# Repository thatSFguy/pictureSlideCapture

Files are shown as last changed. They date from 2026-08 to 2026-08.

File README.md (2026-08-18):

# Film Scanning Rig

> ## ⚠️ Alpha
> It has completed a real production run end-to-end on the author's setup
> (Canon EOS 400D on a Raspberry Pi appliance), but it's been tested on exactly
> one camera and rig, has **no authentication** (designed for a trusted home
> LAN), and interfaces may change. Use at your own risk; expect rough edges.

Digitize 35mm slides and negatives with a tethered Canon DSLR — a web app you
drive from any browser to place a slide, capture it, and review the batch.

> **Status:** proven in production — the author's 35mm slide collection has been
> fully digitized with this rig (hands-free sensor-triggered batches on the Pi
> appliance, hundreds of slides per session). The negatives workflow (RAW preset,
> inversion-ready files) is built but hasn't had a production run yet, and the
> automated XY gantry is deferred. See [CLAUDE.md](CLAUDE.md) for hardware/dev
> notes.

## What it is

A DSLR is mounted over a backlit high-CRI light pad; film is placed in a holder
under the lens and triggered over USB. The host runs a small **stdlib-only
Python web app** (`capture_server.py`) that talks to the camera via `gphoto2`
and serves a phone/tablet/desktop UI. No live view on the target camera (Canon
EOS 400D / Rebel XTi), so the workflow is shoot → review, optimized for volume.

In production it ran fully hands-free: a continuously running motor pushes each
new slide into place, and an optical switch fires the capture as it arrives —
see [Optical sensor trigger](#optical-sensor-trigger-optional) for the mechanism.

## The rig in action

https://github.com/user-attachments/assets/5fd9c2e0-e4c6-4333-81f3-d29baf97b7d2

*The rotary pusher feeding slides while the sensor fires each capture —
fully hands-free.*

## What you need

- A **64-bit-capable Raspberry Pi** (Pi Zero 2 W or newer — the Zero 2 W is the
  reference target), a microSD card, and power. The image is 64-bit (arm64),
  so the single-core ARMv6 Pi Zero W / Pi 1 won't boot it.
- A **Canon DSLR supported by gphoto2** (built and proven on the EOS 400D /
  Rebel XTi) and a USB OTG cable/adapter for the Pi.
- A **high-CRI backlight** under the film, and — for the hands-free feeder —
  the [3D-printed parts](#3d-printed-parts), a small DC motor, and an optical
  break-beam sensor.

No Pi? The app also runs on any Linux/macOS machine — see
[Appendix B](#appendix-b--running-on-a-laptop-instead).

## Quick start — flash the appliance

1. Download the latest `slidescanner-*-arm64.img.xz` from
   [Releases](https://github.com/thatSFguy/pictureSlideCapture/releases) and
   flash it to the SD card with Raspberry Pi Imager.
2. On the camera: set **Communication → PC connection**, the mode dial to
   **M**, and disable auto power-off (an AC dummy-battery coupler beats a
   decades-old battery for long sessions).
3. Boot the Pi. On first boot it raises a **`slidescanner-XXXX`** WiFi access
   point — join it from your phone and enter your home WiFi details.
4. The Pi reconnects to your network. Plug the camera into the Pi, open
   **`http://slidescanner.local:8080`** from any phone/tablet/laptop on the
   LAN, and scan.

Prefer to build the SD image yourself? See
[Appendix A](#appendix-a--building-the-sd-image-yourself).

### Updating

Once deployed, update from the browser: **Setup → System → Check for updates**.
It pulls the latest **release tag** and restarts — no SSH, no reflash. (This
updates the *app* only; changes to the OS image or provisioning still need a new
flashed image.) Requires the Pi to have internet access.

## Using the app — three modes

- **Setup** (once per batch): pick **Slides** or **Negatives** preset, set a
  group name, fine-tune exposure, take a **Test shot** to check it, then
  *Start capturing*. Setup also lists **every group on the device** — reopen an
  old group to review/download it, or delete it outright (renaming a group never
  strands its files).
- **Capture** (the fast loop): large last shot, a glanceable exposure verdict,
  and a running count. Keyboard-first for high volume.
- **Review** (after): thumbnail grid with exposure flags, filter to flagged
  frames, caption/delete/download individual images, download the whole group
  as a zip, or clear the group once it's safely downloaded.

> Tip: `?mode=capture` / `?mode=review` in the URL deep-links a mode — handy as
> a tablet bookmark straight into the capture loop.

**Setup** — presets, group manager, exposure, test shot, sensor trigger and
brightness correction:

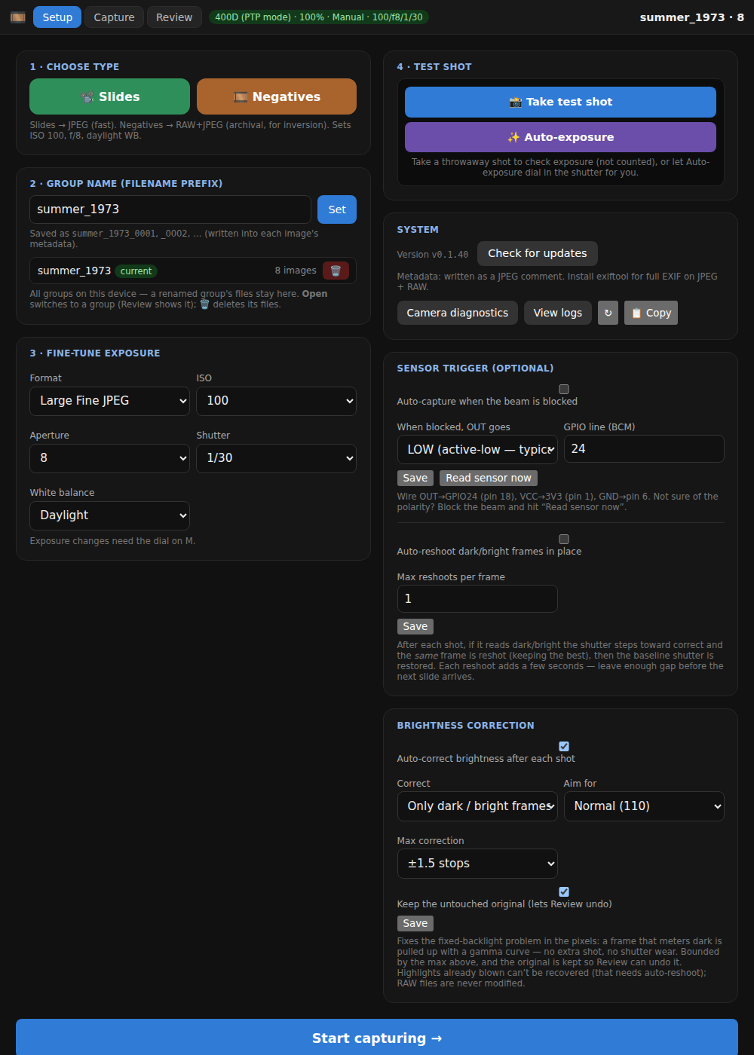
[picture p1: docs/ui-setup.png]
Setup mode: presets, group name + group list, exposure dropdowns, test shot, system, sensor trigger, brightness correction


**Capture** — the whole loop on one screen: last shot, exposure verdict, count,
one big button (or the spacebar, or the optical sensor):

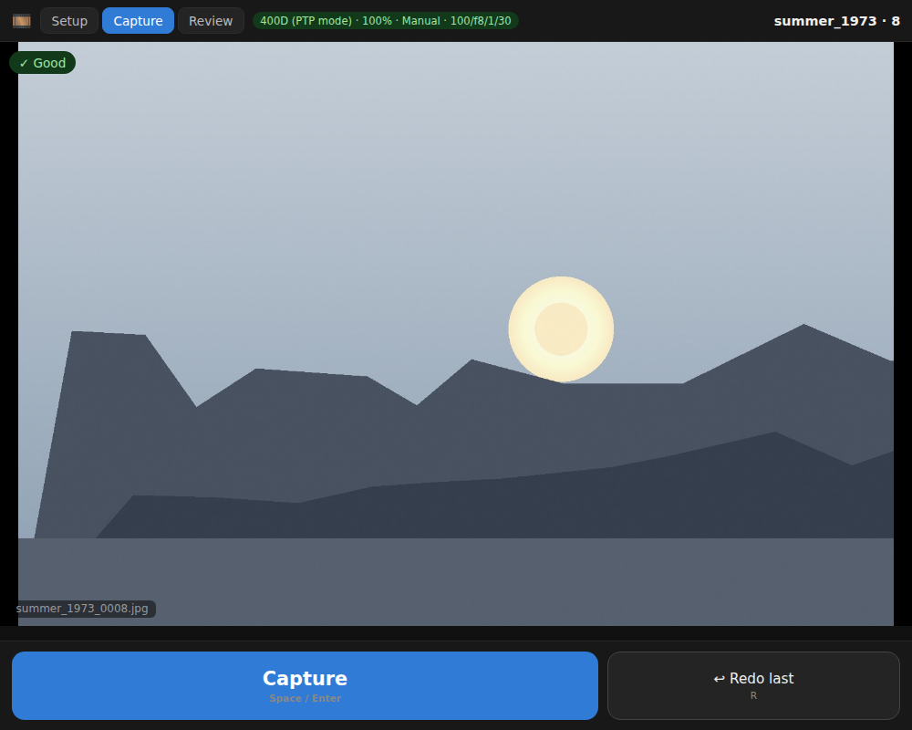
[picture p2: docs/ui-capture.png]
Capture mode: large last-shot preview with exposure chip, running count, Capture and Redo-last buttons


**Review** — the grid with per-frame exposure dots and captions:

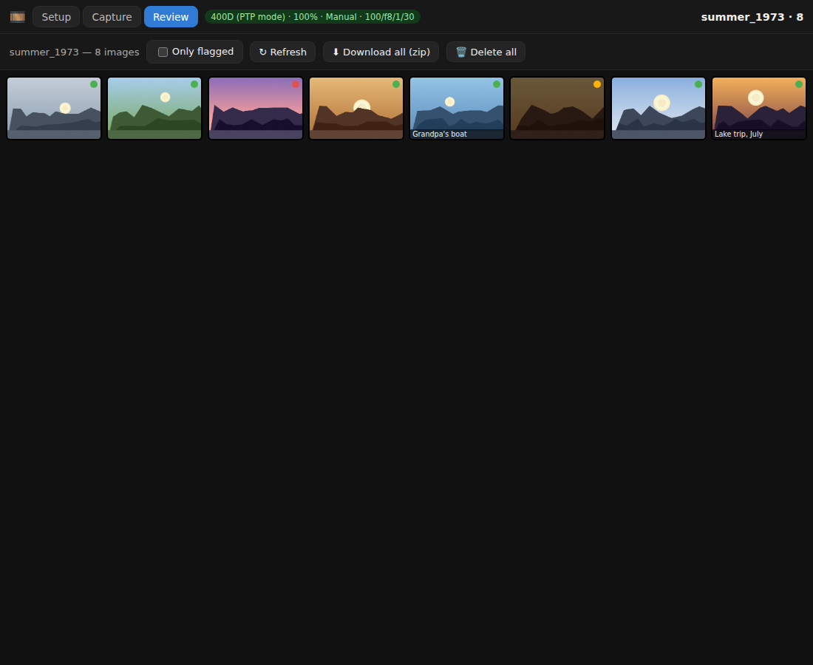
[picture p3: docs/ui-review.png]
Review mode: thumbnail grid with exposure flags, captions, flagged-only filter, zip download and delete-all


*(Screenshots show a demo group served by the app on a dev machine — a stub
camera and generated placeholder images, since the real scans belong to the
family album.)*

### Keyboard shortcuts

| Key | Action |
|-----|---|
| `Space` / `Enter` | Capture |
| `R` / `Backspace` | Redo last (delete + recapture) |
| `←` / `→` | Browse recent (Capture) / prev-next (Review lightbox) |
| `[` / `]` | Go to Setup / Review |
| `Esc` | Close the Review lightbox |
| `Delete` | Delete (Review lightbox) |

## Brightness correction

Slide density varies a lot, and you can't re-dial the light pad for every frame.
Two independent fixes, both automatic — use either or both:

| | Auto-reshoot (optical) | Brightness correction (digital) |
|---|---|---|
| How | Steps the shutter and re-fires the **same** slide, keeping the best | Re-encodes the saved JPEG with a gamma curve onto a target brightness |
| Cost | A whole extra capture cycle (~18 s) + shutter actuation | A few seconds of CPU, in the background — the capture loop never waits |
| Best at | Blown highlights, very dense slides | The routine ±1–2 stop misses |
| Limits | Slow; needs a gap before the next slide | Can't recover detail that was already clipped |

Both live in **Setup**. Brightness correction is on by default for *flagged*
frames only (switch it to "every frame" for an even-looking batch), is bounded
to ±1.5 stops so a legitimately dark night shot can't be wrecked, and keeps the
untouched capture in `captures/originals/` — Review's lightbox has **👁 Original**
to compare and **↩ Undo brighten** to put it back. RAW files are never modified;
for negatives the CR2 is the deliverable and inversion happens in post.

The download-all zip carries those untouched copies in an `originals/` folder, so
downloading and then clearing the group never bakes a correction in permanently.
(Add `?originals=0` to the zip URL to skip them.)

Brightness correction needs one system package (`python3-pil`) that the code
update can't carry — it's a compiled library, not Python source. **You don't
need SSH or a re-flash for it:** if it's missing, Setup shows
**⬇ Install brightness support**, and the scanner fetches it itself over WiFi in
a minute or two (no restart). New SD-card images ship with it already.

## Recommended camera settings

ISO 100, f/8, Manual mode, fixed (Daylight) white balance; **JPEG** for slides,
**RAW+JPEG** for negatives (RAW is essential for inversion). Shutter is the one
value dialed in per session against your light pad using the Test shot +
exposure aid. Focus once, manually, on the film plane. Full rationale in
[CLAUDE.md](CLAUDE.md).

## Optical sensor trigger (optional)

The production rig runs fully hands-free, and the division of labor is simple:

- **The motor just runs.** A continuously running motor — its own power supply
  and a manual speed knob; the Pi neither powers nor controls it — turns a
  rotary arm that pushes the next slide into place in front of the lens,
  revolution after revolution.
- **An optical switch takes the picture.** A 3-pin break-beam sensor is tripped
  once per revolution as the arm passes; that edge is the capture trigger —
  beam blocked → shot fired (`trigger.py`, off by default).

The pace is therefore set on the motor's speed knob, not in software: turn it
down until the camera's sensor-to-shutter latency reliably beats the arm coming
around to push the next slide in. Run that way, the rig captured hundreds of
slides per session for hours with no browser open — that's how the author's
whole collection was scanned.

### Wiring — Raspberry Pi 40-pin header

The board's header usually isn't silk-screened with pin numbers. **Pin 1 is the
square solder pad** (nearest the corner); pins count in pairs down the header —
odd numbers in one row, even in the other.

<p align="center">
  Raspberry Pi 40-pin header pinout; pin 1 (3V3) = VCC, pin 6 = GND, pin 18 (GPIO24) = OUT
</p>

| Sensor wire | Connect to | Physical pin |
|---|---|---|
| **VCC** | **3V3** | **1** |
| **GND** | **Ground** | **6** |
| **OUT** | **GPIO24** | **18** |

⚠️ **Power the sensor from 3V3 (pin 1), not 5V.** The Pi's GPIO is **3.3V-only
and not 5V-tolerant** — a 5V-powered sensor can swing OUT to 5V and damage the
input. Most IR/photo-interrupter modules run fine at 3.3V. Only if yours
*requires* 5V (pins 2/4) do you power it there, and then you **must** drop OUT to
3.3V (voltage divider or level shifter) before pin 18. GPIO24 is used because it
avoids the pins `advance.py` reserves (BCM 17/18/22/27).

### Enabling + polarity

Sensor OUT idle state varies part-to-part, so the trigger polarity is a setting.
In **Setup → Sensor trigger**: tick *Auto-capture when the beam is blocked*, pick
whether OUT goes **LOW** (active-low, the typical open-collector case — default)
or **HIGH** when blocked, set the GPIO line, and **Save**. Not sure which?
**Block the beam and hit “Read sensor now”** — it reads the raw 0/1 so you can
tell active-low (obstructed = 0) from active-high (obstructed = 1). A short
cooldown debounces bounce and avoids a double-fire during the download.

CLI equivalents: `--sensor`, `--sensor-line N` (BCM, default 24),
`--sensor-active-high`. Needs `gpiod` (`sudo apt install gpiod`; already in the
appliance image). Sensor captures share the camera lock with the UI, so a sensor
shot and a button press never overlap. libgpiod **v1 and v2** are both supported
(the CLI syntax differs between them; the app auto-detects the version).

To sanity-check wiring by hand from a shell (libgpiod **v2**, recent Pi OS):

```bash
gpioget -c gpiochip0 24               # prints 24=inactive / 24=active
gpiomon -c gpiochip0 -e falling 24    # block/clear the beam → an event per edge
```

On older **v1** it's `gpioget gpiochip0 24` / `gpiomon --falling-edge gpiochip0 24`.

## 3D-printed parts

Everything printed for the feeder and camera rig is in
[`3D_Files/`](3D_Files/): ready-to-slice **STLs** plus the **FreeCAD sources**
(`.FCStd`), so any dimension can be tweaked for your own camera, motor, or
light before printing.

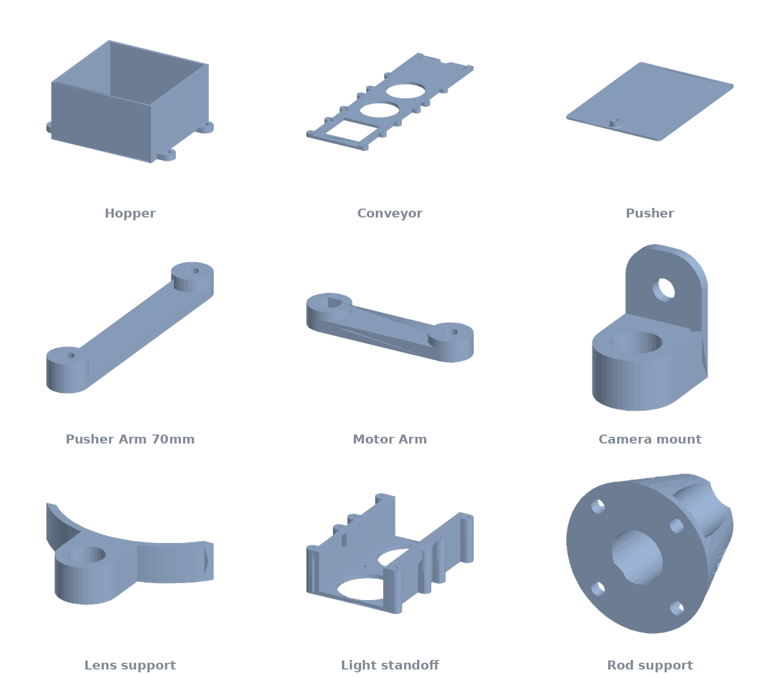
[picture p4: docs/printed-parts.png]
The nine printed parts: Hopper, Conveyor, Pusher, Pusher Arm 70mm, Motor Arm, Camera mount, Lens support, Light standoff, Rod support


| Part | Role |
|---|---|
| Hopper | Holds the stack of slides waiting to be fed |
| Conveyor | The track the slides travel along, over the backlight — the drive motor mounts directly to it |
| Motor Arm | The crank on the motor shaft — this is also what sweeps past the optical sensor once per revolution |
| Pusher Arm 70mm | Connecting link from the crank to the pusher |
| Pusher | The plate that shoves the next slide out of the hopper and into place |
| Camera mount / Rod support | Hold the DSLR on its support rod above the film plane |
| Lens support | Steadies the lens barrel |
| Light standoff | Spaces the backlight below the conveyor |

## Files

| File | Role |
|---|---|
| `capture_server.py` | The web app (HTTP server + embedded UI + all endpoints) |
| `camera.py` | gphoto2 wrapper: detect, get/set config, capture, retries |
| `jpegstats.py` | Pure-stdlib JPEG brightness reader for the exposure aid |
| `brightness.py` | Digital brightness correction: gamma-curves a flagged frame onto a target, keeps the original (needs `python3-pil`) |
| `advance.py` | Auto slide-advance output (stub): capture → advance → repeat, settings-driven (motor+switch / stepper); default off |
| `trigger.py` | Optical-sensor capture trigger: auto-captures on the beam-blocked edge, polarity configurable; default off |
| `scanner.py` | Gantry dead-reckoning batch loop (deferred automation phase) |
| `CLAUDE.md` | Detailed hardware, protocol, and development notes |
| `3D_Files/` | Printable parts for the feeder + camera rig (STL + FreeCAD sources) |

Captured images and per-group sidecars (`captions.json`, `exposure.json`,
`config.json`) are written under `captures/` and are git-ignored, as is
`captures/originals/` (pre-correction copies).

## Post-processing

Negatives require inversion — [Negative Lab Pro](https://www.negativelabpro.com/)
(Lightroom), FilmLab, or darktable's negadoctor. Slides need only minor
correction.

## Roadmap

**The project is done.** It accomplished what it was built for — the author's
35mm slide collection is digitized — and is now in maintenance mode. No further
development is planned.

What it delivered:

- [x] Camera tethering + full-res capture over USB
- [x] Web capture app: presets, exposure aid, digital brightness correction,
      captions, review/cull, export, group management
- [x] Raspberry Pi flash-and-go appliance: CI-built SD image, Comitup WiFi
      provisioning, in-app self-update and diagnostics — no SSH needed
- [x] Physical rig: high-CRI backlight, rotary slide pusher (continuously
      running motor with a manual speed knob — not Pi-controlled), optical
      break-beam capture trigger
- [x] **Production: the whole slide collection scanned end-to-end** —
      multi-hour hands-free sensor-triggered sessions, hundreds of slides per
      session, brightness correction cleaning up the dense frames

Not planned (left here in case the project is ever picked back up):

- Negatives production run — the presets + RAW pipeline are built and should
  work, but never got used in anger
- Auto slide-advance (`advance.py`) — stub + API exist, but the production rig
  proved it unnecessary: the free-running motor plus the optical switch cover it
- Automated XY gantry (GRBL, `scanner.py`) — was the plan for negative strips
- Security hardening (auth/PIN, sudo allowlist, firewall, port 80) — only
  matters if the app ever serves an untrusted network; today it's a trusted
  home LAN behind NAT
- CI on native ARM runners instead of QEMU

## Appendix A — Building the SD image yourself

The prebuilt Release images are produced by CI (GitHub Actions builds a
flashable `.img` on every tag), and the same kit runs locally:
`deploy/setup_pi.sh` installs gphoto2, camera permissions, Comitup for WiFi
provisioning, and the systemd service into a stock Raspberry Pi OS Lite image.
The full two-phase guide is in [`deploy/DEPLOY.md`](deploy/DEPLOY.md).

Note the in-app self-update only ships app code — changes to the OS image or
provisioning need a freshly built (or freshly downloaded) image.

## Appendix B — Running on a laptop instead

Any Linux machine works, and macOS too (Windows doesn't — gphoto2 has no
Windows port, which is much of why the Pi appliance exists). You need:

- [`gphoto2`](http://gphoto.org/) — `sudo apt install gphoto2`
- Python 3 (standard library only — **nothing to `pip install`**)
- Optional: `python3-pil` (`sudo apt install python3-pil`) for automatic
  brightness correction; without it that feature reports itself unavailable and
  everything else runs unchanged.
- Optional: `exiftool` (`sudo apt install libimage-exiftool-perl`) for full EXIF
  metadata; without it the app writes a JPEG comment instead.

```bash
sudo apt install gphoto2
python3 capture_server.py            # then open http://localhost:8080
```

Options: `--port 8080`, `--out-dir ./captures`, `--prefix trip72`, `--no-setup`.

The camera-menu settings from the Quick start (PC connection, dial on **M**,
auto power-off disabled) apply here too. The optical sensor trigger and the
GPIO wiring are Pi-only — on a laptop you capture with the button, the
spacebar, or `?mode=capture` bookmarked on a tablet.

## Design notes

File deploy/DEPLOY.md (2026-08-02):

# Deploying on a Raspberry Pi Zero 2 W

> The CI image is **64-bit (arm64)**. **Minimum board: a 64-bit-capable Pi
> (Zero 2 W or newer)** — the single-core ARMv6 Zero W / Pi 1 are no longer
> supported. The per-shot cycle is partly CPU-bound (Python + exiftool), which
> the Zero 2 W's quad-core A53 handles far better than the old ARMv6 board; the
> rest is bound by the camera's ~1.7 MB/s USB transfer.

Goal — the appliance flow:

> **Flash a card → plug the Pi in → it raises a WiFi AP → connect and enter your
> network → it reconnects → scan at `http://slidescanner.local:8080`.**
> No SSH, no config files, no scripts on the end card.

There's a catch that shapes everything below: a blank card can't `apt install`
Comitup/gphoto2 without a network. So this is **two phases**:

- **Part A — build the appliance image, once.** Install everything on a Pi, then
  save that card as a reusable image.
- **Part B — flash that image and go.** This is the zero-config flow above, and
  it's what you (or anyone) do from then on.

> Why the Zero 2 W's 512 MB RAM is enough: the app is stdlib-only Python, the
> zip download streams, and thumbnails read only the file head. (arm64 uses a
> little more RAM than 32-bit, but the app's footprint is small.) Part of the
> per-shot time is the camera's ~1.7 MB/s USB transfer, which no board fixes.

## Getting the appliance image

Two ways to produce the `slidescanner.img`:

- **CI (recommended).** GitHub Actions builds it for you — see
  [`.github/workflows/build-image.yml`](../.github/workflows/build-image.yml).
  Run it manually (*Actions → Build Pi image → Run workflow*) to get a
  build artifact, or push a `v*` **tag** to attach the compressed image to a
  **Release**. The repo (and your app) are baked in, so there's no private-repo
  copy step. **Set the repo Actions variable `SSH_AUTHORIZED_KEYS`** to your
  public key(s) first (*Settings → Secrets and variables → Actions → Variables*)
  — the appliance's `scanner` user is **key-only**; without it you can't SSH in.
  Then jump to **Part B**.
- **Locally**, following **Part A** below.

## Hardware

- Pi Zero 2 W + a good micro-SD (32 GB+; images live on it).
- **micro-USB-OTG → USB-A adapter** for the camera (data port is micro-USB OTG);
  power via the *separate* PWR port.
- Camera on an **AC coupler**, dial on **M**, Communication = **PC connection**,
  auto-power-off **disabled**.

---

## Part A — Build the appliance image (done once)

You need a network *for this build only*. It won't be needed on the finished
image.

1. **Flash a build card.** Raspberry Pi Imager → *Raspberry Pi OS Lite
   (**64-bit**, Bookworm)* — matches the CI image; requires a 64-bit-capable
   board (Zero 2 W or newer). In OS customisation set: hostname
   `slidescanner`, a username + password, enable **SSH**, and **your WiFi**
   (temporary — for the build).

2. **Get the project onto the Pi.** The GitHub repo is private, so from your
   machine:
   ```bash
   scp -r pictureSlideCapture <user>@slidescanner.local:~/
   ```
   (or authenticate `git`/`gh` on the Pi and clone it.)

3. **Install everything:**
   ```bash
   ssh <user>@slidescanner.local
   cd ~/pictureSlideCapture
   sudo bash deploy/setup_pi.sh
   ```
   This installs gphoto2, the camera udev rule (+ `plugdev`), **Comitup**, the
   hostname, and the `slidescanner` systemd service (port 8080).

4. **Verify** (plug the camera in, power it on):
   ```bash
   systemctl status slidescanner        # active?
   gphoto2 --auto-detect                # camera seen?
   ```
   Browse from another device to `http://slidescanner.local:8080` and take a
   test shot.

5. **Make the image "clean"** so a fresh flash raises the AP instead of joining
   the build WiFi. Remove the saved WiFi so no network is "known":
   ```bash
   nmcli -t -f NAME connection show                 # find your build SSID
   sudo nmcli connection delete "<your-build-ssid>"
   ```
   (Optional tidy-up: `sudo apt clean`, `sudo journalctl --rotate --vacuum-time=1s`.)
   Then shut down: `sudo shutdown -h now`.

6. **Capture the image.** Pull the card, put it in your computer, and save it:
   - Linux/macOS: `sudo dd if=/dev/<card> of=slidescanner.img bs=4M status=progress`
     (then optionally shrink with [PiShrink](https://github.com/Drewsif/PiShrink)).
   - Or use Raspberry Pi Imager / Win32DiskImager "read" to a `.img`.

   `slidescanner.img` is now your reusable appliance image.

---

## Part B — Flash and go (the actual flow)

1. **Flash** `slidescanner.img` to any card (Raspberry Pi Imager → *Use custom*).
   No customisation, no WiFi — flash it as-is.
2. **Plug in** the Pi (and the camera via the OTG adapter). Power on.
3. **Join the AP.** With no known network, Comitup raises WiFi named
   **`slidescanner-XXXX`**. On a phone/laptop, connect to it.
4. **Set your network.** A portal opens (or browse to `http://10.41.0.1`); pick
   your WiFi and enter the password. The Pi joins it and drops the AP.
5. **Scan.** Reconnect your device to that same WiFi and open
   **`http://slidescanner.local:8080`**.

Moving it to a new place later? Same thing — it doesn't recognise the new WiFi,
so it raises `slidescanner-XXXX` again; re-enter credentials.

---

## Everyday use

Setup → pick Slides/Negatives, name the group, dial in the shutter with a Test
shot, Start capturing. Offload with **Review → Download all (zip)**, then delete
the group to free the SD card.

## Service management (on the Pi)

```bash
systemctl status slidescanner
journalctl -u slidescanner -f
sudo systemctl restart slidescanner   # after updating code
```

## Notes / gotchas

- **Port 8080** — Comitup's portal owns port 80, so the scanner URL carries
  `:8080`.
- **Storage** — captures live in `~/captures` on the SD card; offload + delete
  for big RAW jobs (or add a USB stick via a powered OTG hub).
- **Comitup** manages NetworkManager and can be finicky across OS revisions; if
  the AP or reconnect misbehaves, check its docs. Confirm `nmcli device` shows
  wlan0 managed.
- Written without a Pi on hand to test — treat the first build as a shakedown.

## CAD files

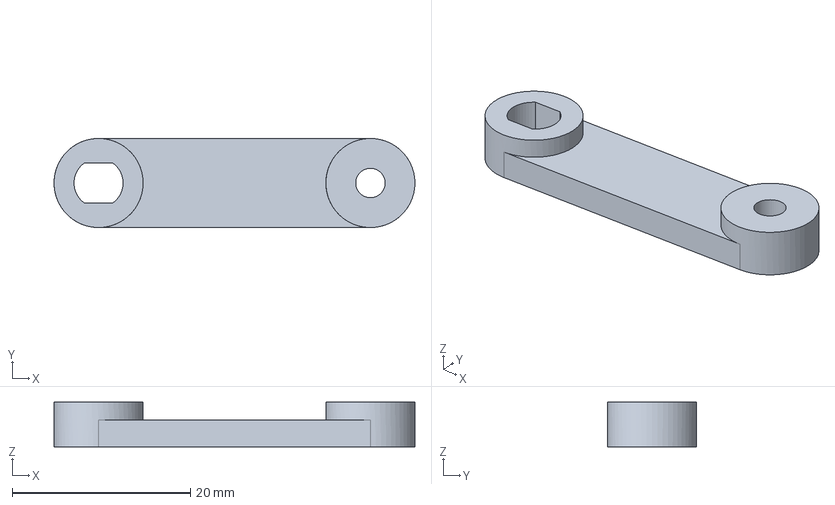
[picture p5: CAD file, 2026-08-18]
3D_Files/Motor Arm.FCStd
40.5 x 10.0 x 5.00 mm

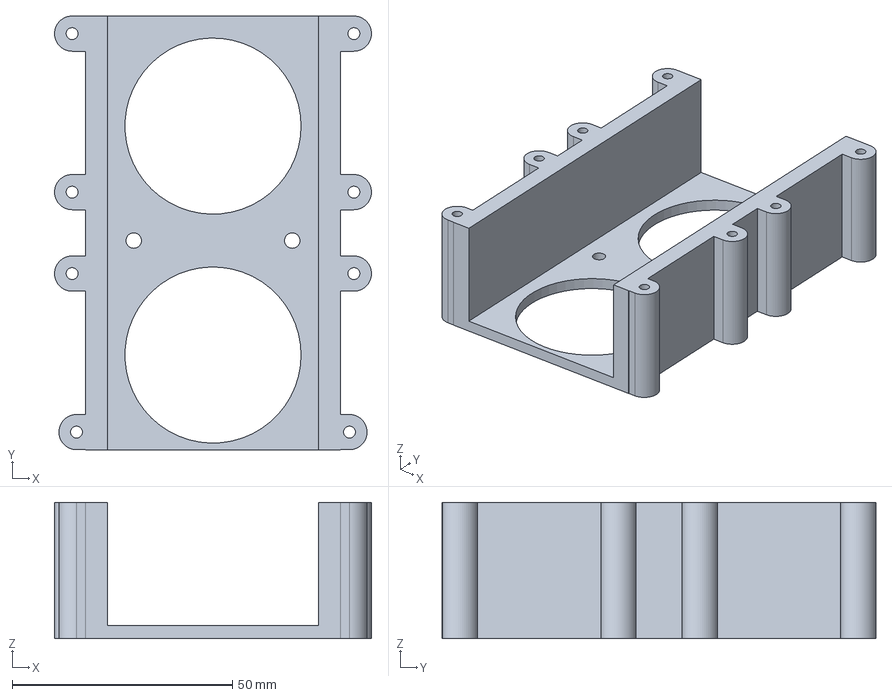
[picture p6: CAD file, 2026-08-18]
3D_Files/light standoff.FCStd
72.0 x 98.6 x 31.0 mm

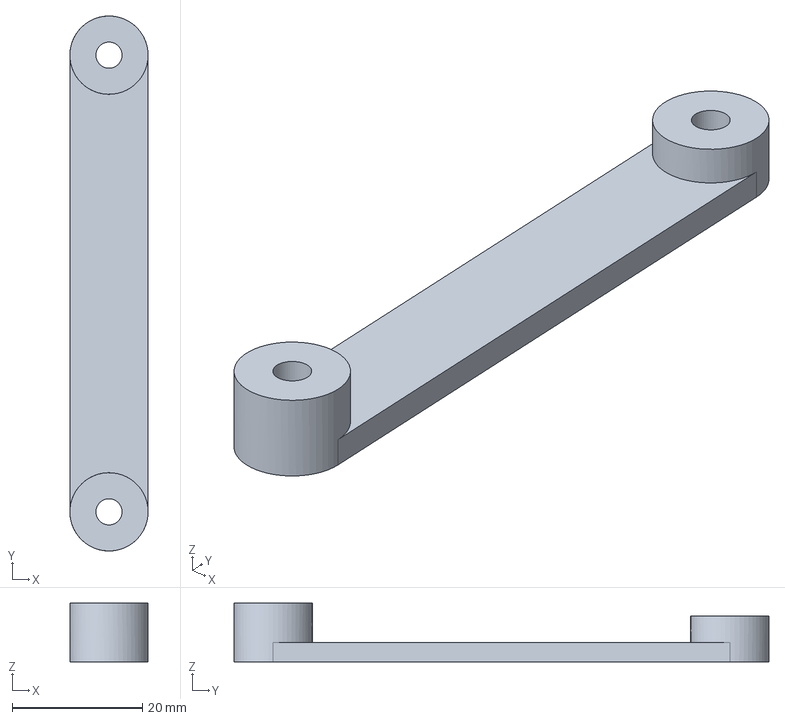
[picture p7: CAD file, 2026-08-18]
3D_Files/Pusher Arm 70mm.FCStd
12.0 x 82.0 x 9.00 mm

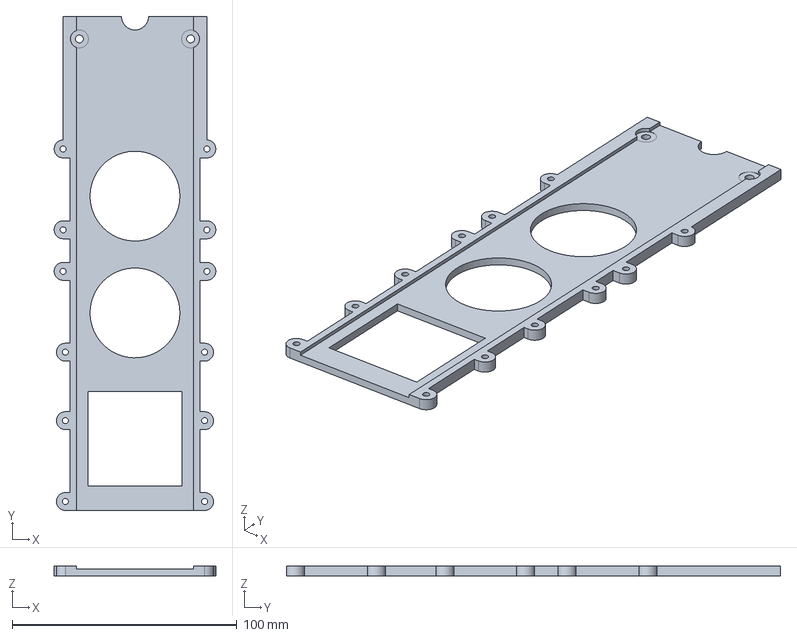
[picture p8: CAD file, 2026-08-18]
3D_Files/Conveyor.FCStd
72.0 x 220.0 x 4.40 mm

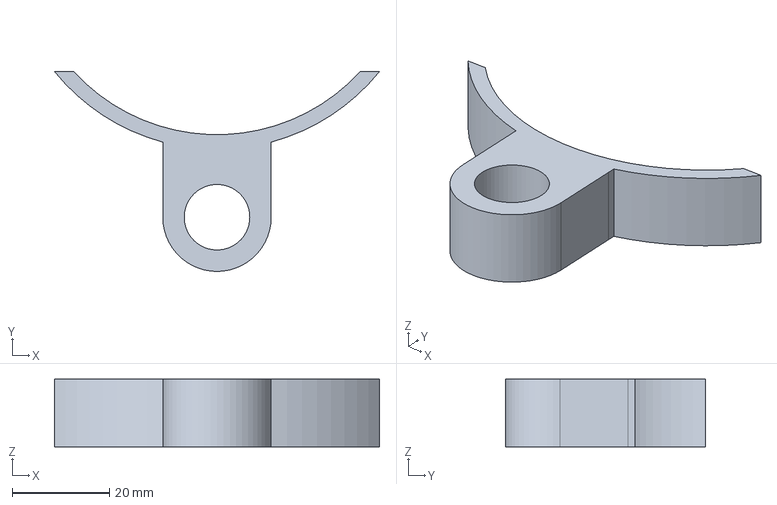
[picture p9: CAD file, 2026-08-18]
3D_Files/Lense Support.FCStd
66.9 x 41.2 x 14.0 mm

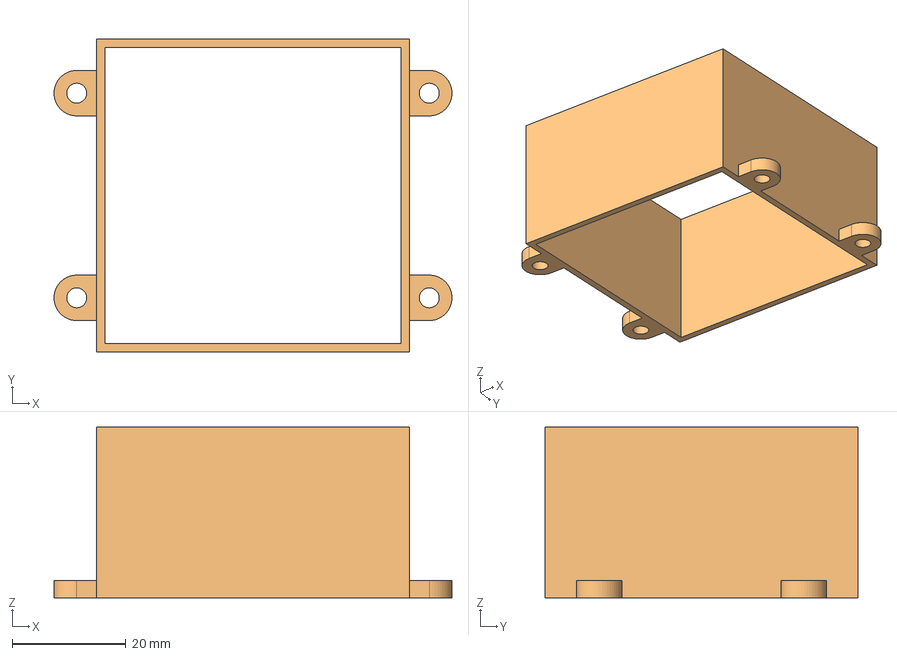
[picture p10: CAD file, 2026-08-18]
3D_Files/Hopper.FCStd
70.0 x 55.0 x 30.0 mm
Hopper

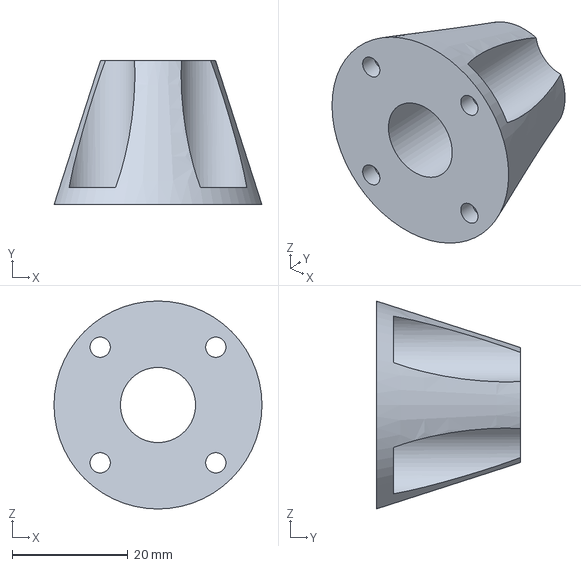
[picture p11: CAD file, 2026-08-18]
3D_Files/Rod support.FCStd
36.0 x 25.0 x 36.0 mm

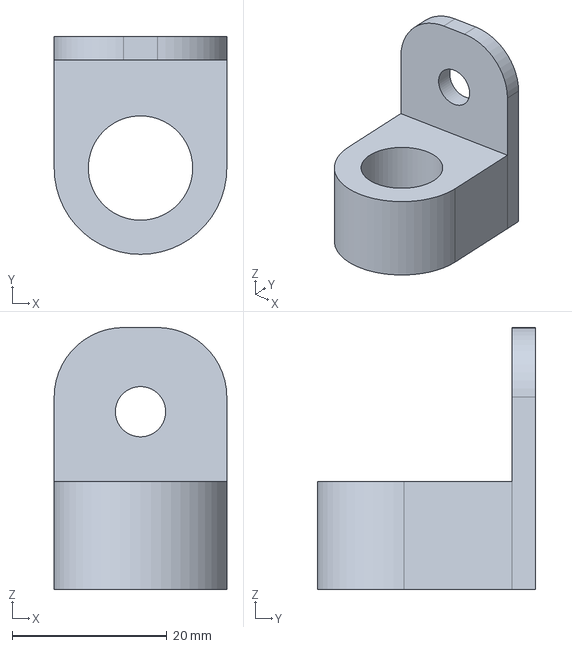
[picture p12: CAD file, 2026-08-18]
3D_Files/camera mount.FCStd
22.3 x 28.2 x 33.9 mm

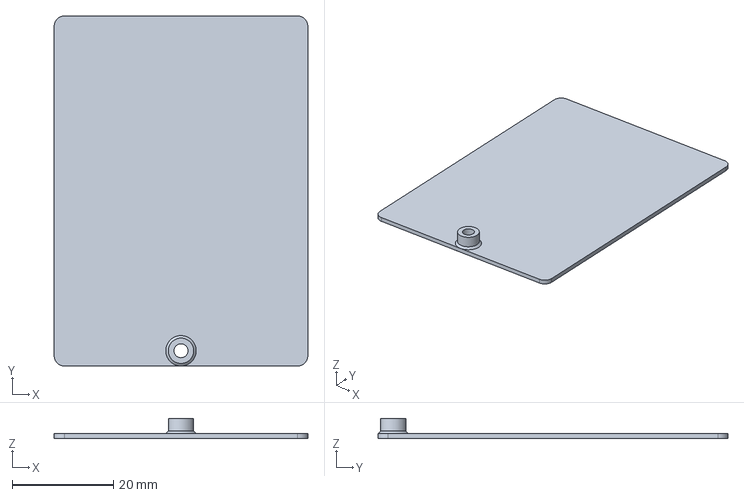
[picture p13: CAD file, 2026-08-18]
3D_Files/Pusher.FCStd
50.0 x 69.0 x 4.00 mm

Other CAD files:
3D_Files/Conveyor.stl
3D_Files/Hopper.stl
3D_Files/Lense Support.stl
3D_Files/Motor Arm.stl
3D_Files/Pusher Arm 70mm.stl
3D_Files/Pusher.stl
3D_Files/Rod support.stl
3D_Files/camera mount.stl
3D_Files/light standoff.stl

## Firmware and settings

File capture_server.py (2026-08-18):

#!/usr/bin/env python3
"""Web-based slide/negative capture UI for the Canon EOS 400D.

Runs on a Linux host (dev box now, Raspberry Pi later) with the camera on USB
and gphoto2 installed. Serves a phone/tablet/desktop page: set the group name
and exposure, place a slide, tap Capture, review/download/delete shots.

Deploy:
    sudo apt install gphoto2            # (optional) exiftool for EXIF metadata
    python3 capture_server.py          # open http://<host>:8080

Stdlib only. Features:
  - Exposure controls (ISO / aperture / shutter / white balance / format),
    dropdowns populated live from the camera. Requires the dial on M.
  - File management: per-image download + delete, and "download all" (zip) for
    the current group.
  - Group prefix: filenames are <prefix>_0001, _0002, ... so a run of slides or
    negatives shares a name. Numbering is per-prefix and resumable.
  - Metadata: the group name is written into each capture (JPEG comment via
    stdlib; full EXIF ImageDescription on JPEG+CR2 if exiftool is installed).
"""

from __future__ import annotations

import argparse
import json
import os
import queue
import re
import sys
import shutil
import subprocess
import tempfile
import threading
import time
import zipfile
from http.server import BaseHTTPRequestHandler, ThreadingHTTPServer
from pathlib import Path
from urllib.parse import unquote, urlparse, parse_qs

import brightness
import jpegstats
from advance import ADVANCE_DEFAULTS, AdvanceError, make_advancer
from camera import Camera, CameraError
from trigger import TRIGGER_DEFAULTS, TriggerError, make_trigger, read_level

# ---- configuration (edit freely) -----------------------------------------
# capturetarget is set per-capture inside cam.capture() (avoids the 400D
# re-enumeration reset), so startup only needs to pick the default format.
STARTUP_SETTINGS = {"imageformat": "L"}
EXPOSURE_KEYS = ["iso", "aperture", "shutterspeed", "whitebalance", "imageformat"]

# Quick-start presets. ISO/aperture/WB/format are sane fixed choices; shutter is
# only a STARTING guess — the light pad's brightness varies, so fine-tune shutter
# per medium in the drawer. Slides -> JPEG (minor correction only); negatives ->
# RAW + JPEG (RAW is essential for inversion, JPEG for instant preview).
PRESETS = {
    "slides": {"iso": "100", "aperture": "8", "whitebalance": "Daylight",
               "imageformat": "L", "shutterspeed": "1/60"},
    "negatives": {"iso": "100", "aperture": "8", "whitebalance": "Daylight",
                  "imageformat": "RAW + L", "shutterspeed": "1/60"},
}
IMAGE_EXTS = {".jpg", ".jpeg"}
RAW_EXTS = {".cr2", ".crw", ".raw"}
PREFIX_BAD = re.compile(r"[^A-Za-z0-9_-]+")

# ---- shared state ---------------------------------------------------------
cam = Camera(retries=3, backoff=0.8, verbose=True)  # fail fast when camera absent
# Persistent gphoto2 session on/off (--no-persist to disable). It removes ~3s of
# process start + PTP setup from in front of every exposure, which is the rig's
# throughput limit; it self-disables if this camera can't hold a session.
cam_lock = threading.Lock()          # camera is single-session: serialize access
_lock_info = {"who": None, "since": 0.0}   # who holds cam_lock + when they took it


def _lock_acquire(who: str, wait: float) -> bool:
    """Acquire cam_lock, recording the holder + start time for diagnostics.
    wait<=0 -> non-blocking; else block up to `wait` seconds."""
    got = (cam_lock.acquire(blocking=False) if wait <= 0
           else cam_lock.acquire(timeout=wait))
    if got:
        _lock_info["who"], _lock_info["since"] = who, time.monotonic()
    return got


def _lock_release() -> None:
    _lock_info["who"], _lock_info["since"] = None, 0.0
    cam_lock.release()


def lock_status() -> dict | None:
    """What holds the camera right now (for busy messages + diagnostics)."""
    who = _lock_info["who"]
    if not who:
        return None
    return {"who": who, "held_s": round(time.monotonic() - _lock_info["since"], 1)}


def _busy_json(handler, msg="camera busy") -> None:
    ls = lock_status()
    if ls:
        msg = f"busy: {ls['who']} ({ls['held_s']}s)"
    handler._json({"ok": False, "busy": True, "error": msg}, 409)


OUT_DIR = Path("./captures")
PREFIX = "slide"
HAVE_EXIFTOOL = shutil.which("exiftool") is not None

# Auto slide-advance output (stub; default "off" == no-op). See advance.py.
ADVANCE = dict(ADVANCE_DEFAULTS)
advancer = make_advancer(ADVANCE)

# Optical-sensor capture trigger (default "off" == no-op). See trigger.py.
# Built lazily in main() once sensor_capture() is defined below.
TRIGGER = dict(TRIGGER_DEFAULTS)
trigger = None

# Auto-reshoot: after a capture, if the frame is flagged dark/over, step the
# shutter one stop toward correct and reshoot the same frame (keeping the best),
# then restore the baseline shutter. Fixes the odd dense slide in place during
# an auto-run without pushing every following slide off. Default off.
RESHOOT = {"enabled": False, "max": 1}

# Digital brightness correction: after a capture, pull a frame that metered
# dark/bright onto a target brightness by re-encoding it with a gamma curve
# (see brightness.py). Complements auto-reshoot — this costs no shutter
# actuation and no extra capture cycle, but can't recover clipped highlights.
BRIGHTNESS = dict(brightness.DEFAULTS)


def set_brightness(cfg: dict) -> dict:
    """Merge + clamp brightness-correction settings."""
    if "enabled" in cfg:
        BRIGHTNESS["enabled"] = bool(cfg["enabled"])
    if cfg.get("mode") in ("flagged", "all"):
        BRIGHTNESS["mode"] = cfg["mode"]
    if "keep_original" in cfg:
        BRIGHTNESS["keep_original"] = bool(cfg["keep_original"])
    for key, lo, hi, cast in (("target", 60, 200, int), ("max_ev", 0.25, 3.0, float),
                              ("quality", 60, 100, int)):
        if key in cfg:
            try:
                BRIGHTNESS[key] = max(lo, min(hi, cast(cfg[key])))
            except (TypeError, ValueError):
                pass
    _persist_config()
    return dict(BRIGHTNESS)


def public_brightness() -> dict:
    """Brightness config plus what the UI needs to explain itself."""
    ok = brightness.available()
    return {**BRIGHTNESS, "available": ok,
            "describe": brightness.describe(BRIGHTNESS),
            "import_error": "" if ok else brightness.import_error(),
            "pending": _post_q.qsize()}


# Correction runs on a worker thread, NOT in the capture path: a 10 MP
# decode+encode is seconds of CPU (measured 4-6 s on the Pi Zero W) against a
# ~8 s capture cycle. Queuing it keeps the Capture button snappy and lets the
# next shot fire while the previous one is still being corrected.
# One worker (not a pool) so a single-core Pi never thrashes; Review's 4 s
# auto-sync surfaces each frame's final state as the queue drains.
# The SAME worker also embeds the EXIF metadata. exiftool is a large Perl program
# whose cold start alone is seconds on a Pi Zero W, and nothing in the capture
# response depends on it, so running it inline just made the operator wait. One
# queue, one job per frame, so each file is touched by exactly one thread and the
# brightness stale-swap token stays valid (a separate metadata job would rewrite
# the file and invalidate it).
_post_q: queue.Queue = queue.Queue()
_sidecar_lock = threading.Lock()      # sidecar JSON is read-modify-write

# Monotonic time the camera last finished talking to USB. Two users: do_capture
# skips its readiness probe when the previous shot is long past, and the sensor
# trigger uses it to date the 400D's re-enumeration transient. 0 = nothing shot
# yet this run, which reads as "long ago" and is the right answer for both.
LAST_USB_DONE = 0.0
# Last successful camera-side status read, reused by the background poll so it
# never has to take the camera lock while a hands-off run is going (see
# read_status_cached). Refreshed at startup and then piggybacked onto captures
# (see _refresh_cam_status) — NOT left to the poll, which never runs a real read
# while the trigger is armed and so would leave the UI stuck on "no camera".
_CAM_STATUS: dict = {"connected": False}
_CAM_STATUS_AT = 0.0          # monotonic time of that read (0 = never)
# How stale the cached camera fields may get during a hands-off run. The refresh
# rides along on a capture we are already holding the lock for, and happens
# AFTER the shutter, so it can never delay an exposure.
STATUS_REFRESH_S = 240.0
# Zip downloads in flight. While one is running the background status poll must
# serve cached camera fields (same rule as an armed trigger): a big group's zip
# pegs the Zero W's single core for minutes, a live gphoto2 status read under
# that starvation runs into its timeout, and the timeout KILLS gphoto2 mid-PTP
# transaction — which wedges the 400D until it is power-cycled. Seen on the
# appliance as "every zip download loses the camera".
_ZIP_STREAMS = 0
_zip_streams_lock = threading.Lock()
# Earliest monotonic time the poll may try a LIVE read to recover a cache that
# says "no camera" (see /api/status). Boot order makes that state routine: the
# Pi is on wall power and boots first, the camera is switched on when the
# operator sits down — so the startup seed reads "no camera", and with the
# trigger armed from persisted settings the poll would otherwise stay
# cache-only forever, leaving the pill blind until a sensor capture that the
# operator (seeing "no camera") never starts.
_CAM_REPROBE_S = 30.0
_next_cam_probe = 0.0
# Shoot blind if the last capture ended longer ago than this. The 400D's
# post-capture bus drop is ~1-2s, so 5s is already a generous margin, and if the
# camera IS unexpectedly away, _grab's no-file retry still recovers.
# This was 20s and that was far too wide: measured on the appliance
# (2026-08-09), edges arrive ~15s apart and the previous capture ends ~5s after
# its own edge, leaving a ~10s gap — inside the window, so the probe ran on
# almost every frame at a cost of 1.6-2.2s. It was BOTH the single largest slice
# of sensor-to-shutter latency and essentially all of its variance (with the
# probe: 4.68-5.16s; the one frame that skipped it: 3.05s).
READY_PROBE_WINDOW = 5.0


def update_exposure(name: str, status: str | None) -> None:
    """Set (or clear) one file's cached exposure verdict, atomically enough for
    the worker and the capture thread to both touch it."""
    with _sidecar_lock:
        ex = load_exposure()
        if status:
            ex[name] = status
        elif ex.pop(name, None) is None:
            return
        save_exposure(ex)


def _post_worker() -> None:
    """Drain the post-capture queue. Never raises — a failed job leaves the
    original capture in place, which is always a valid outcome."""
    while True:
        item = _post_q.get()
        try:
            _post_one(*item)
        except Exception as e:                     # belt and braces: keep draining
            print(f"[post] worker error: {e}", flush=True)
        finally:
            _post_q.task_done()


def _post_one(jpg: Path, raw: Path | None, plan: dict | None,
              token: tuple | None) -> None:
    """Everything a fresh capture needs that the operator doesn't have to wait
    for: the brightness correction, then the EXIF metadata, then a re-meter if
    the pixels moved. Runs off the camera lock, so the next slide can fire while
    this is still going."""
    t0 = time.monotonic()
    if not jpg.is_file():
        return                                     # deleted/redone while queued
    corrected = None
    if plan:
        try:
            corrected = brightness.correct(
                jpg, plan, keep_original=BRIGHTNESS["keep_original"],
                quality=BRIGHTNESS["quality"], expect=token)
        except brightness.BrightnessError as e:
            print(f"[brightness] {jpg.name}: {e}", flush=True)
    # Metadata last, so it is written over the final pixels (a correction
    # rewrites the whole file and would otherwise drop it).
    t_meta = time.monotonic()
    write_metadata(jpg, raw, load_captions().get(jpg.name, ""))
    meta_s = time.monotonic() - t_meta
    if corrected:
        # Re-meter: the correction moved the pixels AND the embedded thumbnail
        # that jpegstats reads, so Review's cached verdict must be refreshed.
        stats = jpegstats.luma_stats(jpg)
        update_exposure(jpg.name, (stats or {}).get("status"))
        print(f"[brightness] {jpg.name}: {corrected['ev']:+.2f} EV "
              f"(gamma {corrected['gamma']}) -> "
              f"{(stats or {}).get('status', '?')}", flush=True)
    print(f"[post] {jpg.name}: meta={meta_s:.1f}s "
          f"total={time.monotonic() - t0:.1f}s (queue {_post_q.qsize()})",
          flush=True)


def plan_brightness(jpg: Path | None, stats: dict | None,
                    derived: bool = False) -> dict | None:
    """Plan a correction for a fresh capture (queuing is the caller's job, as
    part of the one post-capture job). Returns the planned correction for the
    capture response, or None if the frame is left alone.

    Skips RAW-derived previews: with imageformat=RAW the JPEG is only a preview
    extracted from the CR2, and the CR2 is what actually gets developed."""
    if jpg is None or derived or not BRIGHTNESS["enabled"]:
        return None
    if not brightness.available():
        return None
    return brightness.plan(stats, BRIGHTNESS)


def set_reshoot(cfg: dict) -> dict:
    """Merge + clamp auto-reshoot settings."""
    if "enabled" in cfg:
        RESHOOT["enabled"] = bool(cfg["enabled"])
    if "max" in cfg:
        try:
            RESHOOT["max"] = max(1, min(4, int(cfg["max"])))
        except (TypeError, ValueError):
            pass
    _persist_config()
    return dict(RESHOOT)


def set_advance(cfg: dict) -> dict:
    """Merge new advance settings and rebuild the advancer. Lock held.
    Commits only if the new config builds — bad config raises AdvanceError
    without corrupting the live advancer."""
    global ADVANCE, advancer
    merged = {**ADVANCE, **{k: cfg[k] for k in ADVANCE_DEFAULTS if k in cfg}}
    new = make_advancer(merged)               # may raise AdvanceError
    ADVANCE, advancer = merged, new
    _persist_config()
    return ADVANCE


def _advance_once() -> dict:
    """Advance one slide, mapping failures to a result dict (never raises)."""
    try:
        advancer.advance()
        return {"ok": True, "mode": advancer.mode}
    except (AdvanceError, NotImplementedError) as e:
        return {"ok": False, "error": str(e) or "advance not implemented"}


def sensor_capture(edge_ts: float | None = None) -> float:
    """Sensor-trigger callback (runs on the trigger thread). Capture one frame,
    serialized behind the camera lock so it can't overlap a button-press capture
    or an update. Skips the trigger if the camera is busy — never blocks the
    watcher for long. Never raises (the watcher must survive).

    Returns the monotonic time the camera finished with USB, which is what the
    trigger dates the re-enumeration transient from (see trigger.SensorTrigger).
    On a skip or a failure that is simply 'now', so the phantom window covers
    whatever the camera did before giving up."""
    t0 = time.monotonic()
    edge = edge_ts if edge_ts else t0
    if not _lock_acquire("sensor capture", 8):
        print(f"[trigger] camera busy ({lock_status()}) — SKIPPED this slide",
              flush=True)
        return time.monotonic()
    lock_wait = time.monotonic() - t0
    # THE number for a rig whose pusher keeps moving: how long after the sensor
    # tripped did the exposure actually happen. Everything after it is download,
    # by which time the slide is free to move.
    def _shutter():
        print(f"[trigger] SHUTTER at +{time.monotonic() - edge:.2f}s from edge "
              f"(lock wait {lock_wait:.2f}s)", flush=True)
    # Hands-off batch: be patient so a shot fired while the 400D is still
    # re-enumerating rides it out instead of failing (the UI stays fail-fast).
    prev = (cam.retries, cam.backoff)
    cam.retries, cam.backoff = max(cam.retries, 6), max(cam.backoff, 1.0)
    epoch = None
    try:
        res = do_capture(on_shutter=_shutter)
        epoch = LAST_USB_DONE                      # set by a successful capture
        status = (res.get("exposure") or {}).get("status", "?")
        rs = res.get("reshoots") or []
        print(f"[trigger] captured {res.get('name')} [{status}] in "
              f"{time.monotonic() - t0:.1f}s"
              + (f" (reshot x{len(rs)})" if rs else ""), flush=True)
    except CameraError as e:
        print(f"[trigger] capture FAILED after {time.monotonic() - t0:.1f}s: "
              f"{friendly(str(e))}", flush=True)
    finally:
        cam.retries, cam.backoff = prev
        _lock_release()
    # A failed capture never reached the point where USB went quiet, so date the
    # phantom window from now — the camera was on the bus right up to the error.
    return epoch or time.monotonic()


def set_trigger(cfg: dict) -> dict:
    """Merge new trigger settings and (re)start the watcher. Validates by
    building + starting a fresh SensorTrigger before swapping — if it can't
    build/start (bad config or missing gpiomon while enabled), the live watcher
    is left untouched and TriggerError propagates."""
    global TRIGGER, trigger
    merged = {**TRIGGER, **{k: cfg[k] for k in TRIGGER_DEFAULTS if k in cfg}}
    new = make_trigger(merged, sensor_capture)   # may raise TriggerError
    new.start()                                  # may raise (enabled + no tool)
    if trigger is not None:
        trigger.stop()
    trigger, TRIGGER = new, merged
    _persist_config()
    return TRIGGER


def public_trigger() -> dict:
    """Trigger config for the API/UI, plus a human-readable summary."""
    d = dict(TRIGGER)
    d["describe"] = trigger.describe() if trigger is not None else "off"
    d["running"] = bool(trigger is not None and trigger.enabled)
    return d


def read_sensor() -> dict:
    """Current raw sensor level + its interpretation (for polarity setup). Also
    carries the trigger + reshoot + brightness config so the Setup UI can restore
    all three toggles without the (lock-gated) status call — they populate even
    when the camera is busy."""
    base = {"trigger": public_trigger(), "reshoot": dict(RESHOOT),
            "brightness": public_brightness()}
    try:
        lvl = read_level(TRIGGER)
    except TriggerError as e:
        return {"ok": False, "error": str(e), **base}
    obstructed = (lvl == 1) if TRIGGER.get("active_high") else (lvl == 0)
    return {"ok": True, "level": lvl, "obstructed": obstructed, **base}


def sanitize_prefix(s: str) -> str:
    s = PREFIX_BAD.sub("", (s or "").strip())[:40]
    return s or "slide"


def name_re(prefix: str) -> re.Pattern:
    return re.compile(rf"^{re.escape(prefix)}_(\d{{4,}})\.", re.IGNORECASE)


def next_index(prefix: str) -> int:
    rx, hi = name_re(prefix), 0
    for f in OUT_DIR.glob(f"{prefix}_*"):
        m = rx.match(f.name)
        if m:
            hi = max(hi, int(m.group(1)))
    return hi + 1


def group_images(prefix: str) -> list[Path]:
    rx = name_re(prefix)
    imgs = [f for f in OUT_DIR.glob(f"{prefix}_*")
            if f.suffix.lower() in IMAGE_EXTS and rx.match(f.name)]
    imgs.sort(key=lambda f: int(rx.match(f.name).group(1)), reverse=True)
    return imgs


def image_count(prefix: str) -> int:
    return len(group_images(prefix))


def recent_images(prefix: str, limit: int = 24) -> list[str]:
    return [f.name for f in group_images(prefix)[:limit]]


# Any image/RAW file named <prefix>_NNNN.<ext>, capturing the prefix. Greedy, so
# "trip_1972_0001.jpg" groups under "trip_1972" — matching next_index()'s view.
GROUP_RE = re.compile(r"^(.+)_\d{4,}\.", re.IGNORECASE)


def list_groups() -> list[dict]:
    """Every group on disk, newest first. Changing the group name orphans the
    old group's files — still on disk but invisible to a UI that only queries
    the current prefix — so managing them needs a scan, not the current name."""
    groups: dict[str, dict] = {}
    for f in OUT_DIR.iterdir():
        ext = f.suffix.lower()
        if not f.is_file() or ext not in IMAGE_EXTS | RAW_EXTS:
            continue
        m = GROUP_RE.match(f.name)
        if not m:
            continue
        g = groups.setdefault(m.group(1), {"prefix": m.group(1), "count": 0,
                                           "files": 0, "mtime": 0})
        g["files"] += 1
        if ext in IMAGE_EXTS:
            g["count"] += 1
        g["mtime"] = max(g["mtime"], _mtime(f))
    return sorted(groups.values(), key=lambda g: -g["mtime"])


def delete_group(prefix: str) -> list[str]:
    """Remove every file in a group — images, RAW siblings, stashed
    pre-correction originals — and drop its caption/exposure cache entries."""
    rx = name_re(prefix)
    removed = []
    for f in sorted(OUT_DIR.glob(f"{prefix}_*")):
        if not rx.match(f.name):
            continue
        try:
            brightness.discard_original(f)     # pre-correction copy, if any
            f.unlink()
            removed.append(f.name)
        except OSError:
            pass
    if removed:                                # reset the sidecar caches
        caps = load_captions()
        if any(caps.pop(r, None) is not None for r in removed):
            save_captions(caps)
        ex = load_exposure()
        if any(ex.pop(r, None) is not None for r in removed):
            save_exposure(ex)
    return removed
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

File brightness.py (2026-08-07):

#!/usr/bin/env python3
"""Digital brightness correction for captured slide JPEGs.

The light pad is fixed and slide density varies wildly (a hazy sky vs. a dense
Kodachrome shadow), so a single shutter speed leaves some frames a stop or two
dark. Auto-reshoot (capture_server._auto_reshoot) fixes that optically but costs
a whole extra ~18 s capture cycle per slide. This module fixes it in the pixels
instead: meter the frame (jpegstats), then pull it to a target brightness with a
gamma curve and re-encode. No shutter actuation, no operator input.

Design notes:
- **Gamma, not linear gain.** out = 255*(in/255)**g maps the metered mean onto
  the target while pinning 0 and 255, so brightening can never clip highlights.
  A linear gain would blow them out on any frame with a specular hot spot.
- **Correction is bounded** (`max_ev`) and the untouched original is kept, so a
  misjudged frame (a legitimately dark night shot metered as "underexposed") is
  never lost — Review can revert it.
- **RAW is never touched.** For negatives the CR2 is the real deliverable and
  inversion happens in post; only the JPEG is corrected.
- PIL (python3-pil, apt — not pip) does the decode/encode; pure Python can't
  re-encode a 10 MP JPEG in a usable time on a Pi. Everything degrades to a
  no-op when PIL is missing, so the app runs unchanged on a host without it.
- EXIF is spliced over from the original **byte for byte** rather than re-written
  by PIL (keeps MakerNotes, and doesn't depend on PIL's exif-writing quirks),
  with the embedded thumbnail put through the same curve — otherwise Review's
  thumbnail grid and jpegstats (which meters off that thumbnail) would both
  still show the uncorrected frame.
"""

from __future__ import annotations

import math
import os
import shutil
import struct
from io import BytesIO
from pathlib import Path

# Settings shape; merged/clamped by capture_server.set_brightness().
#   mode "flagged" -> only correct frames jpegstats flagged (dark/under/…)
#   mode "all"     -> normalize every frame onto `target` (consistent batch,
#                     but re-encodes frames that were already fine)
DEFAULTS = {
    "enabled": True,
    "mode": "flagged",       # "flagged" | "all"
    "target": 110,           # aim for this metered luma mean (jpegstats scale)
    "max_ev": 1.5,           # never move a frame more than this many stops
    "keep_original": True,   # stash the untouched capture in captures/originals/
    "quality": 92,           # fallback encode quality (original qtables preferred)
}

ORIGINALS_DIR = "originals"

# Below this metered mean the frame is essentially blank (empty slide slot, lens
# cap, dark frame) — "correcting" it just amplifies sensor noise into mud.
MIN_MEAN = 8.0
# Don't burn a re-encode (and its generational quality loss) on a nudge.
MIN_EV = 0.12


class BrightnessError(Exception):
    pass


_import_error = "not attempted"


def available() -> bool:
    """True if the image library needed to correct pixels is installed.

    Catches Exception, not just ImportError: an INSTALLED-but-broken Pillow (a
    C extension that can't find libjpeg, an arch/ABI mismatch) raises other
    types, and this is called from every status poll — letting that escape would
    500 the whole status endpoint over an optional feature. The reason is kept
    for import_error(), because "installed but won't load" and "not installed"
    look identical from the outside and need completely different fixes."""
    global _import_error
    try:
        import PIL.Image  # noqa: F401
        _import_error = ""
        return True
    except Exception as e:
        _import_error = f"{type(e).__name__}: {e}"
        return False


def import_error() -> str:
    """Why the last available() check failed ('' if it succeeded)."""
    return _import_error


def unavailable_reason() -> str:
    available()                      # refresh _import_error
    if _import_error and "No module named" not in _import_error:
        return (f"Pillow is installed but will not load ({_import_error}) — "
                "brightness correction is off.")
    return ("Pillow (python3-pil) is not installed — brightness correction is "
            "off. Install it with: sudo apt install python3-pil")


def describe(settings: dict) -> str:
    """One-line human summary for the UI / diagnostics."""
    if not settings.get("enabled"):
        return "off"
    if not available():
        return "unavailable (python3-pil not installed)"
    scope = "every frame" if settings.get("mode") == "all" else "flagged frames only"
    return (f"on — {scope}, target {int(settings.get('target', 110))}, "
            f"max ±{float(settings.get('max_ev', 1.5)):g} EV")


# ---- deciding what to do --------------------------------------------------

def plan(stats: dict | None, settings: dict) -> dict | None:
    """Decide the correction for a frame from its jpegstats reading.

    Returns {"ev", "gamma", "from_mean", "to_mean"} or None to leave it alone.
    """
    if not settings.get("enabled") or not stats:
        return None
    if settings.get("mode") != "all" and stats.get("status") == "ok":
        return None
    mean = float(stats.get("mean") or 0)
    if not (MIN_MEAN <= mean <= 250):
        return None                      # blank/blown frame: nothing to rescue
    target = float(settings.get("target", DEFAULTS["target"]))
    max_ev = float(settings.get("max_ev", DEFAULTS["max_ev"]))
    ev = math.log2(target / mean)
    ev = max(-max_ev, min(max_ev, ev))   # bounded: a bad call stays recoverable
    if abs(ev) < MIN_EV:
        return None
    to_mean = mean * (2 ** ev)
    # Gamma that lands `mean` exactly on `to_mean` while pinning 0 and 255.
    gamma = math.log(to_mean / 255.0) / math.log(mean / 255.0)
    return {"ev": round(ev, 2), "gamma": round(gamma, 4),
            "from_mean": round(mean, 1), "to_mean": round(to_mean, 1)}


def build_lut(gamma: float) -> list[int]:
    """256-entry gamma curve, clamped to 0..255."""
    return [0] + [min(255, max(0, int(round(255.0 * (i / 255.0) ** gamma))))
                  for i in range(1, 256)]


# ---- JPEG segment surgery (stdlib; keeps EXIF byte-exact) ------------------
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

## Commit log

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2026-07-07 Add Raspberry Pi deploy kit + Pi-readiness fixes
    - deploy/: setup_pi.sh (gphoto2, udev perms, Comitup WiFi provisioning,
    systemd service), slidescanner.service, DEPLOY.md for the Zero 2 W appliance
    (flash -> AP onboarding -> scan at slidescanner.local:8080).
    - capture_server.py: stream download-all zip to a temp file on disk instead of
    buffering in RAM (512 MB Pi safe); thumbnails read only the 128 KB file head.
    - README: deploy section + roadmap update.
    [capture_server.py]
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2026-07-09 Stub the auto slide-advance output (capture -> advance -> repeat)
    Add advance.py: a settings-driven advance abstraction with a no-op default
    (NullAdvancer), a motor+stop-switch implementation via libgpiod
    gpioset/gpiomon (jam-protected by a run timeout, UNTESTED on hardware), and a
    stepper stub that points at GRBL. Tool/hardware checks are deferred to
    advance() time so the mode is selectable from any machine.
    Wire it into capture_server.py: do_capture auto-advances after each capture
    when enabled (failure is reported, never fatal — the image is already saved),
    a POST /api/advance manual endpoint, and advance config through
    GET/POST /api/settings (commits only if the new config builds, so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
    [advance.py, capture_server.py]
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2026-07-09 Fix capture failing on the Pi: enforce capturetarget lazily
    On the appliance the service starts at boot before the camera is connected,
    so the one-shot boot-time STARTUP_SETTINGS never applied and the 400D
    defaulted to Internal RAM (sdram) — which captures but returns no
    downloadable file, surfacing as "captured but no displayable image".
    Apply capturetarget=Memory card lazily on the first capture
    (ensure_capture_target), re-applying after any capture error since a reconnect
    resets the camera's config. Only capturetarget is enforced, so user-chosen
    imageformat/presets are not clobbered. Startup still applies it when the
    camera is present and marks it done.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
    [capture_server.py]
2026-07-09 Add in-app self-update; go public; Alpha warning
    The repo is now public so the appliance can pull with no credentials.
    - Self-update: GET /api/version, GET /api/update (check origin for a newer
    release tag, ancestor-aware so it won't nag a build that already contains
    it), POST /api/update (checkout latest tag + restart). Serialized behind the
    camera lock so it never restarts mid-capture; uses git + passwordless sudo on
    the appliance. Setup gains a System panel: version + "Check for updates" +
    "Update & restart" (polls until the new version is live, then reloads).
    - Provisioning: install git, point the baked repo at the public origin, and
    fetch tags so the appliance can self-upda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
    [capture_server.py]
2026-07-09 Redesign Setup as a responsive card layout; add favicon
    Setup was hard-capped at a 560px centered column, wasting horizontal space
    and giving a cramped, tiny-scrollbar feel on desktop/tablet. Rebuild it as a
    two-column responsive grid of cards (collapses to one column under 820px) in a
    wider 1060px container, so it uses the available width. Add an emoji (🎞️)
    favicon so the browser tab is easy to spot. No JS changes — all element IDs
    preserved.
    [capture_server.py]
2026-07-09 Fix self-update auth: build appliance from a clean public clone
    The update button failed with "could not read Username for github.com":
    arm-runner copied the CI checkout's git config, which embeds an expired
    actions/checkout auth token (http.<url>.extraheader). That stale credential
    made runtime `git fetch` prompt for a username and fail, even on a public repo.
    - provision-image.sh: install the app from a fresh public `git clone` (no CI
    credentials), pinned to the exact built commit, tags fetched. Fallback scrubs
    the credential in place if the clone can't reach the network.
    - capture_server.py: wrap all git calls in `env GIT_TERMINAL_PROMPT=0` (via a
    shared _git_cmd) so git never bloc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
    [capture_server.py]
2026-07-09 Fix capture (atomic capturetarget) + add in-app logs/diagnostics
    Capture fix: the 400D defaults to Internal RAM, which captures but downloads
    no file ("captured but no displayable image"). Setting capturetarget as a
    separate gphoto2 command re-enumerates the camera and resets it back to RAM
    before the next command captures — so the lazy fix never stuck. Set
    capturetarget=Memory card in the SAME invocation as the capture
    (camera.capture prepends --set-config-value); a retry's set is a no-op. Drop
    the lazy ensure_capture_target path and capturetarget from STARTUP_SETTINGS.
    Troubleshooting without SSH: GET /api/logs (journalctl tail) and GET /api/diag
    (system + live camera snapshot incl. the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
    [camera.py, capture_server.py]
2026-07-09 Capture diagnostics, lock-wait to kill spurious "busy", updater rollback
    Capture still returned no file even with capturetarget confirmed = Memory
    card, so make it self-diagnosing: cam.capture() returns gphoto2's stdout, and
    _grab logs the full output + directory listing to the journal and echoes a
    short hint in the /api/test error when nothing downloads.
    "camera busy": the 15s status poll holds the single camera lock ~1-2s; a click
    in that window failed instantly with 409. User-initiated camera ops now wait up
    to 6s for the lock (_with_camera wait=); background status polls pass wait=0 to
    fail fast and skip silently.
    Protect self-update: after checking out the new tag, ast-parse the app m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
    [camera.py, capture_server.py]
2026-07-09 Capture to Internal RAM (sdram), not Memory card
    Logs from the Pi showed the real failure: with capturetarget=Memory card,
    --capture-image-and-download on the 400D writes the frame to the CF card's
    DCIM folder but never downloads it ("New file is in location …/IMG_xxxx.JPG on
    the camera"; ~/captures stays empty). Internal RAM buffers the frame in the
    camera and downloads it straight to the host — reliable and faster, and it
    matches what worked on the dev laptop.
    Default camera.capture() to capturetarget="Internal RAM". Correct the CLAUDE.md
    notes, which had this exactly backwards.
    [camera.py]
2026-07-09 Fix capture: put --filename before --capture-image-and-download
    The real root cause of "captured but no displayable image": gphoto2 2.5.28 on
    the Pi ignores a --filename that comes AFTER --capture-image-and-download, so
    the frame was captured but never downloaded to ~/captures (gphoto2 printed only
    "New file is in location … on the camera"). Both capturetarget values failed
    identically, confirming capturetarget was a red herring. Newer gphoto2 (2.5.32
    on the dev laptop) tolerated the wrong order, which masked it.
    Reorder so settings (--filename, --force-overwrite) precede the capture action.
    [camera.py]
2026-07-09 Add diagnostic /api/debugcapture to find a working capture variant
    gphoto2 2.5.28 on the Pi captures but won't download to --filename regardless
    of arg order or capturetarget. Rather than keep guessing, add a temporary
    POST /api/debugcapture that runs several capture variants (sdram/card, with and
    without --filename, cwd-based download, --wait-event-and-download) and reports
    which one actually writes a local file, plus each one's raw gphoto2 output.
    [capture_server.py]
2026-07-09 Fix capture for real: run gphoto2 from a writable cwd
    The /api/debugcapture matrix nailed it: the identical capture command that
    failed in the service succeeded in the diagnostic — the only difference was the
    working directory. gphoto2 stages the download in its CWD even with an absolute
    --filename, and the systemd service runs with WorkingDirectory=/opt/slidescanner
    (root-owned, not writable by the scanner user), so the frame was captured but
    the download silently dropped. It "worked on the laptop" because that ran from a
    writable repo dir.
    Fix: camera.capture() runs gphoto2 with cwd=dest.parent (the output dir).
    capturetarget and --filename arg-order were both red herrings. Correct the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
    [camera.py]
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2026-07-09 Add Auto-exposure: iterate the shutter to a good exposure
    Automates the manual dial-in loop: shoot a test, read the exposure aid, step
    the shutter one stop longer if dark / shorter if over, repeat until "ok" (or an
    edge / oscillation / 6-step limit). Leaves the camera on the chosen shutter.
    - auto_expose() builds a shutter ladder sorted by seconds and walks it by the
    exposure verdict; POST /api/autoexpose (holds the camera lock for the run).
    - Setup gains an "✨ Auto-exposure" button showing the chosen shutter and the
    path it tried; the shutter dropdown refreshes to the result.
    Meters the whole frame, so a wide black mount border biases it dark — note to
    tighten framing.
    Co-Authore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
    [capture_server.py]
2026-07-09 Center-weighted metering: ignore the slide mount border
    The exposure aid metered the whole frame, so a slide's dark mount border
    dragged the reading down (false "dark", inflated underexposed %) and skewed
    Auto-exposure. Meter only the central 70% of the frame instead: the DC decoder
    now tags each luma block with its MCU column/row, and luma_stats keeps only the
    central region (falls back to full-frame if too few samples). Nudge the "dark"
    threshold up slightly since center readings run higher.
    On the two real slides: the 1/60 shot's false "dark" (border) is gone but it
    still correctly reads dark on content (mean 60), and 1/30 reads ok (mean 96) —
    matching what looked right by eye. No phys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
    [jpegstats.py]
2026-08-02 Add optical-sensor capture trigger (configurable polarity)
    New trigger.py: a settings-driven GPIO input watcher (default off) that
    auto-captures on the unobstructed->obstructed edge of an optical sensor, so a
    slide dropping into position takes the photo with no button press.
    - Polarity is configurable (active_high): sensor OUT idle state varies part to
    part. Default active-low -> falling edge; active-high -> rising edge. Internal
    bias (default pull-up) gives an open-collector sensor a defined idle.
    - Background daemon thread reads one long-lived gpiomon (libgpiod via
    subprocess, same pip-free pattern as advance.py) so no edges are missed;
    cooldown_s debounces and prevents a double-f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
    [capture_server.py, trigger.py]
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2026-08-02 Fix GPIO for libgpiod v2 (recent Pi OS): version-aware CLI
    Recent Raspberry Pi OS ships libgpiod v2, whose gpioget/gpiomon/gpioset syntax
    is incompatible with v1: the chip now needs -c and edges use -e rising/falling.
    The old v1-only commands failed on v2 with "cannot find line 'gpiochip0'" (v2
    parses the chip name as a line name), so neither the sensor trigger nor the
    motor advance worked.
    Add gpiocli.py: detects the installed libgpiod major version once and builds the
    correct argv for get/mon/set; parse_level() handles both the v1 ("0"/"1") and v2
    ("24=inactive") output formats. trigger.py and advance.py now build all GPIO
    commands through it, so they run on either version.
    Also drops ad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
    [advance.py, gpiocli.py, trigger.py]
2026-08-02 Fix GPIO permission denied (chip is root:gpio)
    /dev/gpiochip* is owned root:gpio (mode 660), and the appliance service user
    (scanner) wasn't in the gpio group, so gpioget/gpiomon failed with
    "unable to open chip '/dev/gpiochip0': Permission denied" — the sensor trigger
    and motor advance couldn't touch GPIO.
    Two-pronged fix:
    - gpiocli gains a sudo fallback: it probes once whether a direct gpioget is
    denied and passwordless sudo is available, and if so prepends `sudo -n` to
    gpio commands. scanner already has NOPASSWD sudo, so this works on an
    already-flashed box via the in-app update — no reflash. On a dev box with
    direct GPIO access (or where sudo would prompt) it runs the comman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
    [advance.py, gpiocli.py, trigger.py]
2026-08-02 Fix auto-exposure "camera busy" from post-capture USB re-enumeration
    The 400D re-enumerates on the USB bus after each SDRAM capture, so the command
    auto-exposure issues immediately afterward (changing the shutter) could land
    mid-reset and fail with a transient claim/IO error, surfaced as "camera busy".
    A single capture never hits this (nothing follows it right away); only the
    back-to-back auto-exposure loop does — matching the report of one snapshot then
    a busy error.
    auto_expose() now settles ~1.2s after each test shot (letting the re-enumeration
    finish) and temporarily raises the camera's retry budget (retries>=6,
    backoff>=1.2) for the duration, restoring it after. Safe because auto_exp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
    [capture_server.py]
2026-08-02 Keep Review live: auto-sync grid without manual refresh
    Review was a static snapshot — it only loaded on entering the view or via the
    Refresh button (lightbox deletes spliced out live, but nothing else). So frames
    added by an ongoing auto-run, or deletes made from another tab/device, didn't
    show until a manual refresh.
    Add syncReview(): while Review is the active, visible view it re-polls
    /api/images every 4s and re-renders only when the set actually changed (compared
    via a name/caption/exposure signature), and also refreshes on tab focus /
    visibility change. Paused while the lightbox is open so it never disrupts an
    in-progress caption or delete.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
    [capture_server.py]
2026-08-02 Auto-reshoot dark/bright frames in place + Review "Delete all"
    Auto-reshoot (opt-in, default off): after a capture, if the exposure aid flags
    the frame dark/under/over/bright, step the shutter one stop toward correct and
    reshoot the SAME frame up to `max` times (default 1), keeping the best result,
    then restore the baseline shutter so one dense slide doesn't drift the rest of
    the batch. Runs in do_capture(), so it covers both button and sensor-triggered
    captures. Reshoot candidates capture to temp stems and the winner is promoted
    onto the frame, guaranteeing a correction never leaves it worse than the
    original. Reuses the post-capture re-enumeration settle + retry patience so the
    immediate s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
    [capture_server.py]
2026-08-02 Fix sensor-trigger Save stuck on "Saving…"
    The Save button in Setup → Sensor trigger POSTs /api/trigger and the sensor
    config actually saved server-side, but the JS then called d.trigger.describe()
    as a function — describe is a plain string from public_trigger(), so the call
    threw TypeError before updating the status text, leaving it stuck on "Saving…".
    Drop the parens (d.trigger.describe) and wrap saveTrigger() in try/catch so a
    JS/network error can never strand the message again.
    [capture_server.py]
2026-08-02 Fix trigger latency + "exposure n/a" on reshot frames
    Trigger latency (2-3s from beam-break to capture): the watcher read a
    long-lived streaming gpiomon via `for line in proc.stdout`, which suffers from
    gpiomon's pipe block-buffering plus Python read-ahead, so edge lines arrived
    seconds late. Switch to one `gpiomon --num-events 1` per event: the process
    exits the instant the edge fires (flushing immediately), so the capture is
    prompt. The only gap is the ~tens-of-ms restart between events, which lands
    during the post-capture cooldown when no new slide is due.
    "exposure n/a": a reshoot capture fires immediately after the first, inside the
    400D's USB re-enumeration window; when it errored, th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
    [capture_server.py, trigger.py]
2026-08-02 Add camera readiness probe; gate rapid re-shots on it
    The 400D drops off the USB bus for ~1-2s after each SDRAM capture, so a rapid
    follow-up shot (auto-reshoot, auto-exposure) fired on a blind 1.2s sleep could
    still land mid-re-enumeration and fail ("captured but no displayable image").
    Add Camera.ready() (one cheap config-read probe, no retry/cwd) and
    Camera.wait_ready(timeout, poll, settle) which pauses briefly then polls ready()
    until the camera answers again — waiting exactly as long as needed. Replace the
    blind AUTOEXP_SETTLE_S sleeps in _auto_reshoot and auto_expose with
    cam.wait_ready() (after the first shot, and again before firing the follow-up),
    so rapid re-shots only fire once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
    [camera.py, capture_server.py]
2026-08-02 Fix stale Review thumbnails after delete + recapture
    Group filenames are reused (numbering restarts after a delete-all), so a new
    frame can land on an old name (slide_0001.jpg). The Review grid's <img> URLs
    were just /thumb/<name>, which the browser caches by URL — so it showed the OLD
    cached thumbnail for the new file. In-app Refresh re-fetched the list but reused
    the same image URLs, so only a full browser refresh cleared it.
    read_images now returns each file's mtime, and the grid thumbnails + lightbox
    cache-bust with ?v=<mtime>. A replaced file gets a new URL (fresh fetch);
    unchanged files keep their URL (still cached, still fast). mtime is also folded
    into the sync signature so the li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
    [capture_server.py]
2026-08-02 Recover a sensor shot that fires mid-re-enumeration
    The sensor-trigger capture fires immediately on beam-break with no readiness
    check — so a trigger landing while the 400D is still re-enumerating from the
    previous shot (tight margin between the ~5s capture and ~6s advance) could
    download nothing ("captured but no displayable image") and drop the slide.
    _grab() now, when nothing downloads, waits for the camera (wait_ready) and
    re-fires exactly once before giving up. Costs nothing on a normal shot (only
    triggers on the empty-download miss) and doesn't loop (bounded to one retry).
    [capture_server.py]
2026-08-02 Persist settings, diagnose the camera lock, lighten the preview
    Three related fixes from a hands-off batch run:
    1. Settings reset every restart: sensor-trigger, auto-reshoot, and advance
    config lived only in memory, so the self-update restart (or any restart) reset
    them to off — hence re-checking the boxes constantly. Now persisted to
    config.json and restored at startup. The trigger + reshoot toggles also load
    from the lock-free /api/trigger, so the UI shows their real state even when
    the camera is busy (the status poll, which carried reshoot, is lock-gated and
    returns nothing useful while busy).
    2. "Busy" while idle: a stuck/slow camera op held cam_lock with no visibil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
    [camera.py, capture_server.py]
2026-08-02 Fix missed sensor edges during captures; add in-app log view + copy
    Complete misses: since v0.1.20 the watcher fired one gpiomon per event, so it
    was NOT watching during a capture — an edge (next slide) that arrived while a
    shot was downloading (~5s) was lost entirely. Revert to a single long-lived
    streaming gpiomon that sees every edge (edges during a capture buffer and are
    processed right after), but keep it prompt with `stdbuf -oL` + readline() (the
    buffering that caused the original lag was libc block-buffering + Python
    read-ahead, not the streaming itself).
    Troubleshooting: log every step of the trigger path — watcher command, each edge
    detected / ignored-by-cooldown, capture start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
    [capture_server.py, trigger.py]
2026-08-02 Speed up captures: wait-ready before the shot + fail-fast reshoot
    Live-run logs showed captures taking 18-26s (should be ~5s), which is why slides
    advanced past mid-capture and got "missed":
    1. do_capture now probes camera readiness (wait_ready settle=0) BEFORE the first
    shot. The 400D re-enumerates after every SDRAM capture, so firing blind right
    after the previous slide downloaded nothing and forced the slow
    wait-then-refire recovery (~18s for even an [ok] frame). Waiting for the
    camera first lets the shot succeed on the first try.
    2. Auto-reshoot failed every time on this body ("could not claim") AND burned
    ~18s doing so, because it bumped retries to 6 x 1.2s backoff. Cut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
    [capture_server.py]
2026-08-02 Stop losing sensor slides dropped during a capture
    The sensor trigger read gpiomon and ran the ~18s capture on one thread, so
    any edge that arrived mid-capture was buffered then discarded by the
    post-capture cooldown re-arm. A slide staged while the previous capture was
    still running was silently dropped — the "sometimes doesn't fire" symptom,
    visible in the log as an "edge ignored (within cooldown)" after every shot.
    Split into a reader thread (streams edges in real time, sets a coalesced
    "capture requested" flag) and a worker thread (captures one at a time). An
    edge during a capture now leaves the flag set, so the worker fires again the
    moment it's free. The old cooldown becomes a short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
    [trigger.py]
2026-08-02 Fix sensor trigger + camera-busy: swallow re-enumeration phantom edge, retry device-busy
    Two real bugs the v0.1.27 logs exposed:
    1. The `verify` I added read the beam with `gpioget` on the same line the
    reader's long-lived `gpiomon` already holds, so every queued-slide check
    failed "sensor read failed" and dropped the slide — worse than before.
    Root insight: the edge that lands the instant each ~18s capture finishes is
    NOT a slide but the 400D's USB re-enumeration transient (it recurs at the
    exact completion second every time, which a hands-off operator with no
    completion signal can't produce). Drop the gpioget verify entirely; instead
    the worker settles after each sh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
    [camera.py, capture_server.py, trigger.py]
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2026-08-07 Correct slide brightness in software, installable without SSH
    Slide density varies per frame and the light pad can't be re-dialed for
    every shot, so captures land a stop or two dark. Auto-reshoot fixes that
    optically but costs a whole extra ~18s capture cycle per slide; this
    fixes it in the pixels instead, with no shutter actuation.
    brightness.py meters the frame (jpegstats), then pulls it onto a target
    with a gamma curve: g is solved so the metered mean lands on target,
    which pins 0 and 255 so brightening can never clip highlights the way a
    linear gain would. Bounded to +/-1.5 EV and skipped on near-blank frames,
    so a legitimately dark slide can't be wrecked. Re-encodes with the
    camera's o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
    [brightness.py, capture_server.py]
2026-08-07 Fix brightness install: restart to pick up the package, and log why
    v0.1.31's installer failed on the appliance. apt actually succeeded
    ("python3-pil is already the newest version"), but the running process
    still could not import it, so the feature stayed off with no usable
    explanation. Three separate defects.
    1. importlib.invalidate_caches() does not reliably make a package that
    appeared after interpreter startup importable, so the service has to
    restart. Rather than restart blindly, ask a fresh interpreter: if
    `sys.executable -c "import PIL.Image"` succeeds, only this process is
    stale, so take cam_lock (never restart mid-capture) and restart, with
    the UI waiting for the app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
    [brightness.py, capture_server.py]
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
